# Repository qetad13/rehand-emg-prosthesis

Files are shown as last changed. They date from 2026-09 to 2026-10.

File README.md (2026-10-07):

# ReHand — EMG 기반 손가락 동작 인식 의수 제어

> 졸업작품 · **2026.01 – 2026.10** · 4인 팀 (팀장)

전완부 표면 근전도(sEMG) 4채널을 XIAO ESP32-S3로 1 kHz 샘플링하고, **보드 위에서 직접 CNN 추론**으로 손가락 동작 8가지를 분류해 ESP-NOW로 의수 보드에 명령을 보내는 시스템입니다.
PCB 설계 → 데이터 수집 GUI → PyTorch 학습 → C 코드 자동 생성 → 온디바이스 실시간 추론까지 전 과정을 직접 구현했습니다.

| 항목 | 내용 |
|---|---|
| 입력 | 표면 EMG 4채널, 1000 Hz, 12-bit ADC |
| 출력 | 휴식 / 엄지 / 검지 / 중지 / 약지 / 소지 / 주먹 / 집게 (8클래스) |
| MCU | Seeed XIAO ESP32-S3 (듀얼코어, 추론·샘플링 코어 분리) |
| 모델 | STFT 스펙트로그램 + 3층 Conv2D CNN, 파라미터 6,368개 (float 약 25 KB) |
| 통신 | ESP-NOW (근전도 보드 → 의수 보드, 2바이트 {명령 번호, 힘 세기}) |
| 성능 | 미사용 순서 세션 기준 1초 창 정확도 **97.3%**, 실시간 제어 지연 중앙값 **290 ms** (빠른 모드) |

---

## 시스템 구조

```mermaid
flowchart LR
    subgraph Arm["전완부"]
        S1[EMG 센서 ×4]
    end
    subgraph EMG["근전도 보드 (자체 PCB + XIAO ESP32-S3)"]
        ADC["ADC 1 kHz<br/>(Core 1)"] --> F["IIR 필터<br/>HPF 20 Hz + Notch 60 Hz"]
        F --> RB[링 버퍼]
        RB --> INF["STFT → CNN 추론<br/>(Core 0, FreeRTOS task)"]
        INF --> V["휴식 게이트 + 투표<br/>(오작동 억제)"]
        RB --> ST["힘 세기<br/>(최근 0.2초 RMS / 휴식 RMS)"]
    end
    subgraph Hand["의수 보드"]
        R[ESP-NOW 수신] --> SV[서보 제어]
    end
    S1 -->|Molex SPOX 3핀| ADC
    V -->|ESP-NOW 명령 1~8| R
    ST -->|힘 세기 1~100| R

    subgraph PC["PC (오프라인)"]
        GUI["수집 GUI<br/>(PySide6)"] --> CSV[(CSV + 라벨 순서)]
        CSV --> TR["PyTorch 학습<br/>train_emg.py"]
        TR -->|"emg_model.h<br/>emg_test_vectors.h"| INF
    end
    ADC -.->|MODE_RECORD, USB 시리얼| GUI
```

### 데이터 파이프라인

1. **수집** — 펌웨어를 `MODE_RECORD`로 올리고 GUI가 5초 힘주기 / 5초 쉬기를 안내하며 녹화 (1세션 = 8동작 × 10초 = 80초)
2. **전처리** — 4차 Butterworth HPF 20 Hz + 60 Hz 노치 (PC와 ESP32에서 **같은 SOS 계수**로 계산)
3. **특징** — 창마다 채널별 z-score 정규화 → Hamming 창 STFT → 주파수 밴드 평균 → log 파워
4. **모델** — Conv(8) → Conv(16) → Conv(32) → Global Avg Pool → FC. BatchNorm은 내보낼 때 Conv에 접어(fold) 넣음
5. **내보내기** — 가중치·필터 계수·클래스 이름을 C 헤더로 생성, PC 예측값을 **골든 테스트 벡터**로 함께 내보냄
6. **온디바이스** — Core 1은 1 kHz 샘플링만, Core 0은 추론 태스크. 출력은 투표 로직을 거쳐 ESP-NOW로 전송

---

## 폴더 구조

```
rehand-emg-prosthesis/
├─ hardware/                 KiCad 프로젝트 (근전도 보드)
│  ├─ v1/                    초기 보드: 회로도 · PCB · gerber/
│  └─ v2/                    현재 보드 (배터리 · 버튼 추가): 회로도 · PCB · gerber/
├─ collector/                데이터 수집 GUI (PySide6 + pyserial)
│  └─ emg_collector_v4.py
├─ training/                 학습 + ESP32용 C 헤더 생성
│  ├─ train_emg.py           python train_emg.py [--fast]
│  ├─ data/Fixed/            고정 순서 세션 15개 (학습/검증)
│  ├─ data/Random/           무작위 순서 세션 5개 (테스트 전용)
│  ├─ output/                정확 모드 결과 (report, 그림, 모델)
│  └─ output_fast/           빠른 모드 결과
├─ firmware/                 Arduino (XIAO ESP32-S3)
│  ├─ esp32_emg_realtime/    녹화 · 센서 점검 · 실시간 판단 · 재생 (모드 전환)
│  ├─ esp32_emg_test/        PC ↔ ESP32 결과 일치 검증 (골든 테스트)
│  └─ esp32_emg_bench/       단계별 연산 시간 측정 (STFT+CNN vs 시간영역 특징)
└─ docs/
   ├─ hand_board_patch.md    의수 보드 ESP-NOW 수신부 수정 내역
   └─ images/                결과 그림
```

---

## 하드웨어

<p align="center">
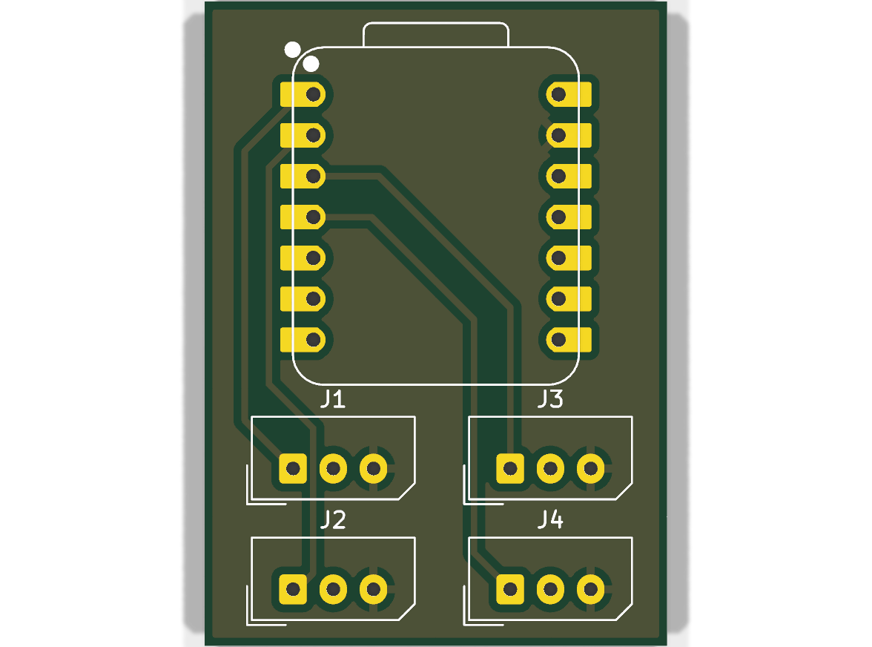
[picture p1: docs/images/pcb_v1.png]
  
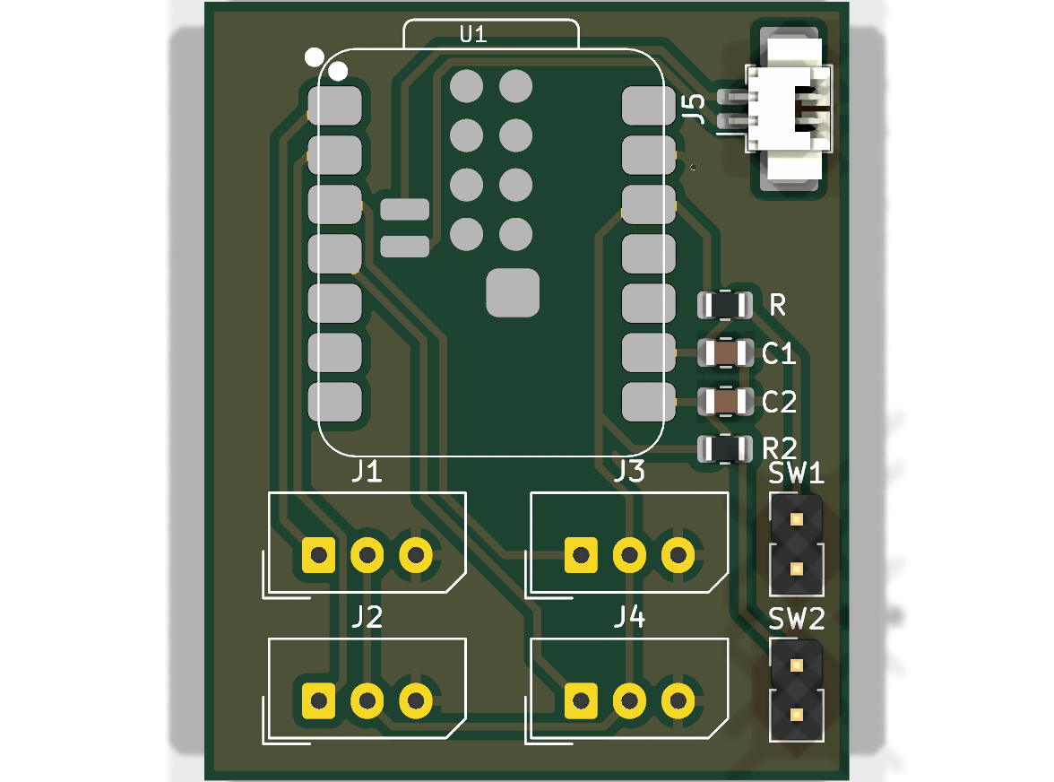
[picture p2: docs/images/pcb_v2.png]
  
  <br><sub>왼쪽 v1 · 오른쪽 v2 (현재)</sub>
</p>

| | v1 | v2 (현재) |
|---|---|---|
| 크기 | 28.75 × 40 mm | 33.2 × 40 mm |
| MCU 실장 | XIAO ESP32-S3 DIP 풋프린트 | XIAO ESP32-S3 **SMD** 풋프린트 (하단 BAT 패드 사용) |
| 센서 입력 | Molex SPOX 3핀 ×4 (신호 / 3V3 / GND → A0~A3) | 동일 |
| 전원 | USB | **J5 PicoBlade 2핀** → XIAO BAT 패드 (배터리 연결) |
| 입력 버튼 | 없음 | **SW1 · SW2** (D7 · D8), 풀업 저항 + 디바운스 커패시터 (0805) |
| 회로도 | [schematic_v1.svg](docs/images/schematic_v1.svg) | [schematic_v2.svg](docs/images/schematic_v2.svg) |

- 브레드보드 배선에서 생기던 접촉 불량과 잡음을 줄이기 위해 전용 보드로 제작
- v2에서는 착용형으로 쓰기 위해 배터리 입력을 추가하고, 버튼 2개를 하드웨어 풀업·RC 디바운스와 함께 넣음
  - **SW1**: 근전도 모드 ↔ 매크로 모드 전환 (보드 LED가 켜지면 매크로 모드)
  - **SW2**: 매크로 모드에서 다음 동작 선택 (명령 11~19). 근전도 모드에서는 사용자 보정 기능 자리로 예약
  - 버튼은 별도 FreeRTOS 태스크가 10 ms마다 읽어 1 kHz 측정 루프에 영향이 없음. 스위치가 없는 보드에서는 시리얼 `1`/`2` 또는 BOOT 버튼(짧게/길게)으로 대신 조작

---

## 힘 세기 → 의수 속도

CNN은 창마다 채널을 z-score 정규화한 뒤 **모양**만 보기 때문에 "얼마나 세게" 힘을 줬는지는 알 수 없습니다.
그래서 동작 종류는 CNN이, 세기는 신호 크기로 따로 재서 함께 보냅니다.

- **세기(배)** = 최근 0.2초 RMS ÷ 휴식 RMS, 4채널 중 최댓값 (`emg_strength()`)
- **세기(%)** = 휴식 게이트 크기를 0%, 동작별 기준을 100%로 놓고 환산 → 1~100으로 전송 (휴식·매크로 모드는 0 = 기본 속도)
- **동작별 기준**: 같은 힘이어도 동작마다 신호 크기가 크게 달라서(엄지 약 6배, 약지 약 40배) 녹화 20세션에서 "인식 직후 0.5초 평균"의 중앙값을 동작별로 사용
- **안정화**: 동작 시작 순간에는 바로 반영하고 이후 지수 평활(α = 0.5). 필요하면 약/강, 약/중/강 단계 출력 + 히스테리시스로 전환 가능
- **보정 지원**: 동작이 끝날 때마다 시리얼에 `세기 요약`(처음 0.5초 평균 / 이후 평균)을 출력해 센서를 다시 붙였을 때 기준을 쉽게 다시 맞춤
- 인식 직후 첫 값은 근전도가 아직 커지는 중이라 들쭉날쭉하므로, 의수 보드는 첫 값으로 속도를 고정하지 않고 움직이는 동안 계속 갱신하도록 함 → [docs/hand_board_patch.md](docs/hand_board_patch.md)

---

## 성능

평가는 **학습에 쓰지 않은 Random 세션 5개**(동작 순서를 무작위로 섞어 녹화, 총 6.7분)로 했습니다. 고정 순서만 학습하면 "순서"를 외울 수 있기 때문에 테스트 세트를 순서가 다른 세션으로 분리했습니다.

### 분류 정확도

| 지표 | 정확 모드 | 빠른 모드 |
|---|---|---|
| 창 단위 정확도 (8클래스) | **97.3%** | 95.1% |
| 창 단위 정확도 (휴식 제외 7동작) | 94.6% | 93.7% |
| 수축 구간 다수결 | 97.5% (39/40) | 97.5% (39/40) |

클래스별 (정확 모드): 휴식 100%, 엄지 92%, 검지 98%, 중지 95%, 약지 100%, 소지 92%, 주먹 100%, 집게 85%

<p align="center">
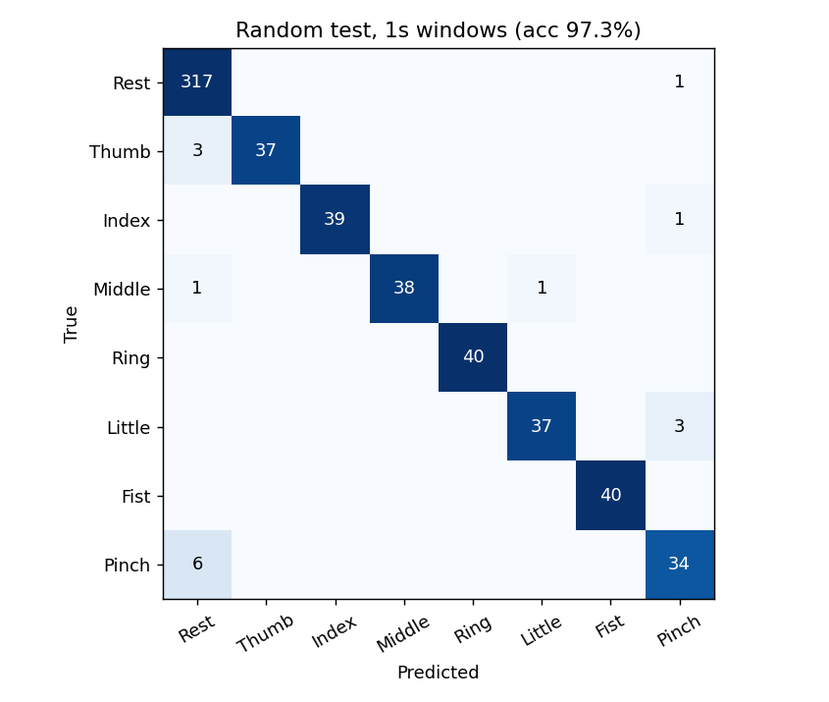
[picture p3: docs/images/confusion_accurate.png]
  
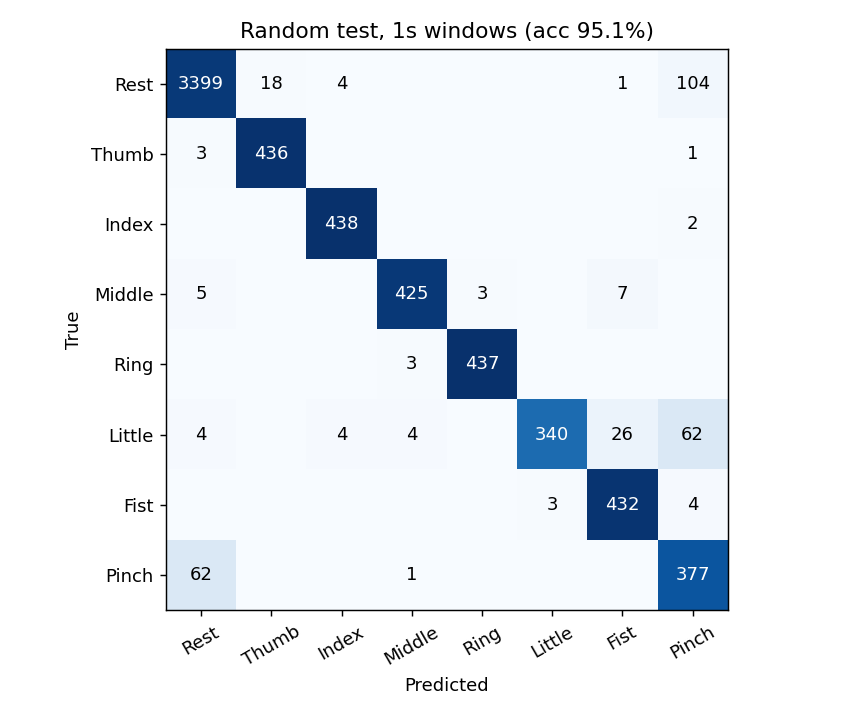
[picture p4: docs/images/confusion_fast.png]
  
</p>

### 실시간 제어 (실제 판단 주기와 투표 로직을 그대로 재현한 시뮬레이션)

| 지표 | 정확 모드 | 빠른 모드 |
|---|---|---|
| 판단 창 / 주기 | 1.0 s / 500 ms | 0.5 s / 50 ms |
| 근전도 시작 → 올바른 출력 (중앙값) | 1007 ms | **290 ms** |
| 근전도 시작 → 올바른 출력 (90%) | 1482 ms | 790 ms |
| 힘 뺀 뒤 출력 해제 (중앙값) | 394 ms | **243 ms** |
| 동작 인식 성공 / 놓침 | 35 / 0 | 35 / 0 |
| 잘못된 손가락 출력 (6.7분) | **0회** | 6회 |
| 휴식 중 오작동 비율 | 0.0% | 0.4% |

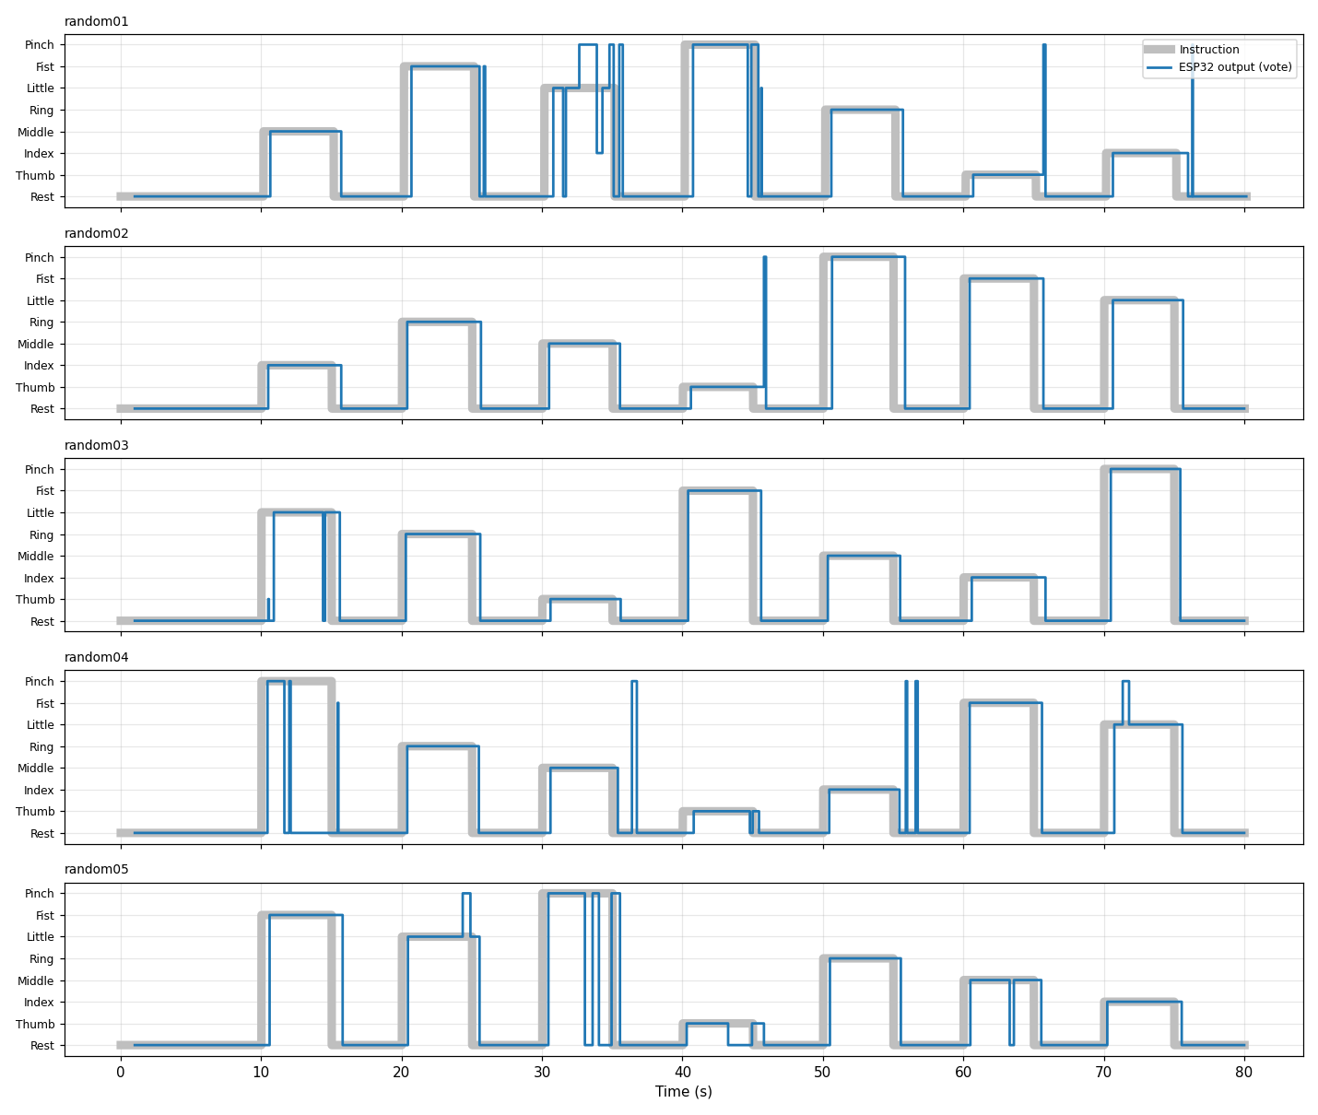
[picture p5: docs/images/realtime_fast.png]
realtime


### 경량화

| | 기존 MATLAB 모델 | 이 프로젝트 (정확) | 이 프로젝트 (빠른) |
|---|---|---|---|
| 1회 판단 곱셈 수 | 약 231 M | 0.44 M | 0.14 M |
| 파라미터 | – | 6,368 (≈25 KB) | 6,368 (≈25 KB) |

연산량을 **약 500~1600배** 줄여 ESP32-S3에서 50 ms 주기 추론이 가능해졌습니다. 펌웨어는 추론이 주기 안에 끝나지 않으면 `판단 건너뜀` 카운터로 표시합니다.

---

## 트러블슈팅

### 1. 여러 채널이 같은 필터 상태를 공유하는 문제
- **증상**: 채널을 4개로 늘리자 한 채널에 힘을 줘도 다른 채널 파형이 같이 흔들림
- **원인**: 사용하던 `EMGFilters` 라이브러리가 LPF/HPF/노치 필터의 내부 상태를 **파일 전역 변수**로 갖고 있어, 채널마다 객체를 만들어도 상태가 섞임
- **해결**: 필터 상태를 클래스 멤버로 옮겨 인스턴스마다 독립되게 수정 ([EMGFilters.h](firmware/esp32_emg_realtime/EMGFilters.h))

### 2. 녹화 중 샘플 손실 → 라벨 밀림
- **증상**: 80초 녹화인데 CSV 줄 수가 모자라거나, 뒤쪽 동작 구간이 앞 동작 신호와 섞임
- **원인**: 샘플링과 USB 시리얼 전송을 같은 루프에서 하다 보니, PC 쪽 읽기가 잠깐 멈추면 `Serial.write`가 막혀 1 kHz 샘플링이 밀림. 또 GUI가 녹화를 시작하기 전에 쌓인 옛 데이터가 녹화 앞부분에 섞임
- **해결**
  - 샘플링(Core 1)과 전송(Core 0)을 분리하고 16k 샘플 링 버퍼로 연결
  - 1초 이상 밀리면 오래된 데이터를 버리고 실시간으로 다시 맞춤, 이때 LED를 켜서 불량 녹화를 바로 알 수 있게 함
  - 학습 코드에서 길이가 5초 ± 5%를 벗어난 구간은 자동으로 제외

### 3. 시리얼 전송 중 깨진 값
- **증상**: `73-6.0`처럼 두 값이 붙은 줄 때문에 CSV 파싱 실패
- **해결**: 숫자로 변환 불가능한 값은 NaN 처리 후 앞뒤 값으로 채움 (`pd.to_numeric(errors="coerce").ffill()`)

### 4. 센서 접촉 불량 데이터가 학습을 망침
- **증상**: 특정 세션이 섞이면 전체 정확도가 크게 떨어짐. 원인을 찾아보면 전극이 떠 있던 세션
- **해결**: 학습 전 자동 품질 검사 추가
  - 수축 구간 RMS가 휴식 대비 1.3배 미만인 세션 자동 제외
  - 어떤 동작에도 반응하지 않는 채널 / 휴식 때부터 잡음이 큰 채널 경고
  - 펌웨어 `MODE_CHECK`로 녹화 전에 채널별 흔들림 · 클리핑 확인

### 5. 학습과 실시간 입력이 달라서 생기는 정확도 저하
- **증상**: PC 검증 정확도는 높은데 보드에 올리면 판단이 불안정
- **원인**: 녹화용 코드와 판단용 코드의 ADC 읽기·필터 경로가 달랐음
- **해결**
  - 녹화(`MODE_RECORD`)와 판단(`MODE_RUN`)을 한 스케치로 합치고 같은 `readEmgInput()`을 사용
  - PC 필터도 `filtfilt`(양방향) 대신 기기와 같은 인과 필터 `sosfilt`를 파일 처음부터 연속 적용
  - 학습 스크립트가 PC 예측 확률을 `emg_test_vectors.h`로 내보내고, `esp32_emg_test`에서 ESP32 결과와 비교 → **PC와 C 구현의 확률 차이까지 검증**

### 6. MATLAB 모델을 MCU에 올릴 수 없는 문제
- **원인**: 기존 모델은 1회 판단에 약 2.3억 번 곱셈 → ESP32에서 실시간 불가
- **해결**: 입력을 STFT 밴드 평균(채널당 22×24 또는 13×14)으로 줄이고, 3층 소형 CNN + Global Average Pooling으로 FC 파라미터를 최소화. BN을 Conv에 접어서 추론 시 연산 제거
- `esp32_emg_bench`로 필터 / STFT / CNN 단계별 시간과 시간영역 특징(MAV·RMS·WL·ZC·SSC) 방식을 비교해 구조를 결정

### 7. 반응 속도 vs 오작동 트레이드오프
- **문제**: 1초 창 · 0.5초 주기는 오작동이 0회지만 반응이 1초 가까이 늦어 의수로 쓰기 답답함
- **해결**: 0.5초 창을 50 ms마다 판단하는 빠른 모드 추가, 대신 늘어나는 오판을 규칙으로 억제
  - **휴식 게이트**: 모든 채널 RMS가 휴식 기준의 2배 미만이면 무조건 휴식
  - **히스테리시스 투표**: 켜기는 3회 연속, 다른 동작으로 전환은 5회 연속, 끄기는 휴식 1회
  - 라벨을 창의 "끝부분" 상태 + 사람 반응 지연(50~150 ms)으로 맞춰 힘을 빼면 빨리 풀리도록 학습
- **1차 결과**: 제어 지연 1007 ms → **290 ms**, 해제 394 ms → 104 ms. 하지만 6.7분 동안 엉뚱한 손가락 출력이 **15회**
- **2차 조정**: 출력이 짧게 바뀌었다 돌아오는 오출력을 줄이기 위해 출력을 바꾸는 조건을 더 엄격하게 함
  - 다른 동작으로 전환: 5회 → **8회 연속**
  - 끄기: 휴식 1회 → **3회 연속** (휴식 판단 한 번에 껐다 켜지는 깜빡임 방지)
  - **최소 유지 시간 0.5초**: 출력이 바뀐 뒤 10회 판단 동안은 다시 바꾸지 않음
  - PC 시뮬레이션(`vote_sequence`)과 ESP32(`emg_vote_update`)에 같은 규칙을 넣고 파라미터는 `emg_model.h`로 자동 생성
- **최종 결과**: 제어 지연 **290 ms 유지**, 오출력 15회 → **6회**, 대신 해제는 104 ms → 243 ms로 늘어남

### 8. 시리얼 출력 때문에 추론이 밀림
- **증상**: PC에서 시리얼 모니터를 닫으면 판단 주기가 늘어짐
- **원인**: USB CDC 버퍼가 차면 `Serial.printf`가 블로킹
- **해결**: 판단 모드에서 `Serial.setTxTimeoutMs(0)`로 PC가 안 읽으면 출력 버림, 빠른 모드는 출력 변경 시 + 1초마다만 출력

### 9. 의수가 명령을 받지만 움직이지 않음
- **원인 1**: 의수 보드의 ESP-NOW 콜백이 플래그만 세우고 `loop()`에서 확인하지 않음
- **원인 2**: 수신 조건이 `cmd <= 6`이라 새로 추가한 주먹(7) · 집게(8)가 무시됨
- **해결**: `loop()`에서 플래그를 확인해 실행 (서보 버스를 WiFi 태스크 콜백 안에서 쓰지 않도록), 범위를 1~8로 확장. 근전도 보드는 0.5초마다 현재 명령을 재전송해 패킷 손실에도 복구 → [docs/hand_board_patch.md](docs/hand_board_patch.md)

---

## 실행 방법

### 1. 설치
```bash
pip install -r training/requirements.txt -r collector/requirements.txt
```

### 2. 데이터 수집
1. `firmware/esp32_emg_realtime/esp32_emg_realtime.ino`에서 `#define RUN_MODE MODE_CHECK`로 업로드 → 채널 상태 확인
2. `MODE_RECORD`로 업로드 후 `python collector/emg_collector_v4.py`
3. 고정 순서는 `training/data/Fixed/`, 무작위 순서는 `training/data/Random/`에 저장 (순서는 `_order.txt`로 자동 기록)

### 3. 학습
```bash
python training/train_emg.py          # 정확 모드
python training/train_emg.py --fast   # 빠른 모드
```
생성된 `emg_model.h`, `emg_test_vectors.h`가 `firmware/`의 세 스케치 폴더에 자동 복사됩니다.

### 4. 검증 및 실행
| 스케치 | 용도 |
|---|---|
| `esp32_emg_test` | PC 결과와 일치 여부 확인 (`8 / 8 통과`) |
| `esp32_emg_bench` | 단계별 연산 시간 측정 |
| `esp32_emg_realtime` (`MODE_RUN`) | 실시간 판단 + ESP-NOW 전송 |
| `esp32_emg_realtime` (`MODE_REPLAY`) | 센서 없이 저장 데이터로 판단 흐름 확인 |

Arduino IDE 설정: 보드 `XIAO_ESP32S3`, `USB CDC On Boot: Enabled`

---

## 변경 이력

| 날짜 | 변경 내용 |
|---|---|
| 2026-10-07 | **힘 세기 전송**: 동작 종류와 함께 힘 세기(1~100)를 2바이트 패킷으로 전송, 의수 보드에서 서보 속도로 사용. 동작별 100% 기준, 평활화, 단계 출력 옵션, 세기 요약 출력 추가 |
| 2026-10-06 | **근전도 / 매크로 모드**: SW1로 모드 전환, SW2로 매크로 동작(명령 11~19) 선택. 버튼 전용 FreeRTOS 태스크, 시리얼·BOOT 버튼 대체 입력 |
| 2026-10-02 | **빠른 모드 투표 규칙 강화**: 끄기 3회 연속, 전환 8회 연속, 최소 유지 0.5초 추가 → 오출력 15회 → 6회 (6.7분 기준) |
| 2026-09-30 | **PCB v2**: XIAO SMD 실장, 배터리 커넥터, 버튼 2개(풀업 + RC 디바운스) 추가 |
| 2026-09-30 | 저장소 공개: 하드웨어 · 수집 GUI · 학습 · 펌웨어 · 문서 정리 |

---

## 기술 스택
`Python` `PyTorch` `NumPy/SciPy` `PySide6` · `C/C++ (Arduino, FreeRTOS)` · `KiCad`

## 라이선스 / 출처
- `firmware/esp32_emg_realtime/EMGFilters.*`: OYMotion Inc. (BSD-3-Clause), 채널별 상태 분리 수정

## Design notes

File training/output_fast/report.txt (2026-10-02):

=== Random 세션(순서 섞은 데이터) 시험 결과 ===
1초 단위 정확도 (휴식 포함 8종): 95.1%
1초 단위 정확도 (휴식 제외 동작 7종): 93.7%
한 번 힘주기(수축 구간) 다수결: 97.5% (39/40)
클래스별 1초 단위 정답률: Rest 96%, Thumb 99%, Index 100%, Middle 97%, Ring 99%, Little 77%, Fist 98%, Pinch 86%

=== 실시간 흉내 (50ms마다 판단 / 켜기: 최근 3번 중 3번, 바꾸기: 연속 8번, 끄기: Rest 3번 연속, 최소 유지 0.5초, 휴식 게이트 2.0) ===
안정 구간 정확도: 96.5%
휴식 중 잘못 움직임 판단 비율: 0.4%
힘주기 시작 -> 올바른 판단까지 걸린 시간(중앙값): 0.48초
힘 빼기 -> 손가락 판단이 풀릴 때까지 걸린 시간(중앙값): 0.54초
근전도 시작 -> 올바른 판단 (제어 지연): 중앙값 290ms, 90% 790ms
근전도 끝 -> 풀림: 중앙값 243ms
손가락 동작 인식: 35번 성공 / 0번 놓침
엉뚱한 손가락이 켜진 횟수: 6번 (총 6.7분 동안)

=== ESP32 부담 ===
가중치 수: 6368개 (float 기준 약 25KB)
한 번 판단에 곱셈 약 0.14백만 번 (MATLAB 모델은 약 231백만 번)
최고 시점: epoch 14

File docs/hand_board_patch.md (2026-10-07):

# 의수 보드 코드 수정 (ESP-NOW 명령 실행)

현재 의수 코드는 ESP-NOW로 명령을 **받기만 하고 실행하지 않습니다.**
`onEspNowReceive()`가 `g_newEspNowCommand`를 true로 바꾸지만, `loop()`에서 이걸 확인하는 곳이 없습니다.

`loop()`를 아래처럼 바꾸면 됩니다. (추가된 부분은 가운데 블록 하나)

```cpp
void loop() {
  static uint32_t last_cmd_ms = 0;

  if (HOMING_isBusy()) {
    while (Serial.available()) { Serial.read(); }
    vTaskDelay(pdMS_TO_TICKS(5));
    return;
  }

  // ---- ESP-NOW로 받은 명령 실행 (근전도 보드가 0.5초마다 보냄) ----
  if (g_newEspNowCommand) {
    g_newEspNowCommand = false;
    static uint8_t lastEspNowCmd = 0;
    uint8_t cmd = g_receivedCommand;
    if (cmd != lastEspNowCmd) {      // 같은 명령이 반복해서 오면 무시
      lastEspNowCmd = cmd;
      Serial.print("[ESP-NOW] Received command: ");
      Serial.println(cmd);
      executeHandCommand(cmd);
    }
  }

  checkAndEnforceSoftLimits();
  checkSerialHandCommand();
  vTaskDelay(pdMS_TO_TICKS(5));
}
```

참고: 명령 실행을 수신 콜백(`onEspNowReceive`) 안에서 하지 않고 `loop()`에서 하는 이유는,
콜백은 WiFi 태스크에서 돌기 때문에 거기서 서보 버스(시리얼, 뮤텍스)를 쓰면 WiFi가 멈출 수 있어서입니다.

## 근전도 보드가 보내는 명령 (9/24 기준, 8가지)

| 근전도 판단 | 명령 번호 |
|---|---|
| 엄지 | 1 |
| 검지 | 2 |
| 중지 | 3 |
| 약지 | 4 |
| 소지 | 5 |
| 휴식 | 6 |
| 주먹 | 7 |
| 집게 | 8 |

**주의:** 의수 코드의 수신 콜백 `onEspNowReceive()`에 `if (cmd >= 1 && cmd <= 6)`가 있으면
7, 8이 무시됩니다. `cmd <= 8`로 바꿔주세요. 시리얼 테스트용 `checkSerialHandCommand()`도 `'8'`까지 받게 바꾸면 편합니다.

번호를 바꾸려면 근전도 보드의 `esp32_emg_realtime.ino`에서 `handCmdFor()`만 수정하면 됩니다.

## 힘 세기 받기 (세게 = 빠르게)

근전도 보드가 이제 **2바이트 {명령 번호, 힘 세기}** 를 보냅니다. (판단할 때마다, 빠른 모드 기준 50ms마다)

| 힘 세기 값 | 의미 |
|---|---|
| 1~100 | 손가락 동작 중. 클수록 세게 힘을 준 것 |
| 0 | 세기 정보 없음 (휴식, 매크로 모드) -> 기본 속도로 움직이면 됨 |

의수 코드에서 바꿀 곳은 세 군데입니다. (변수/함수 이름은 실제 의수 코드에 맞춰 주세요)

```cpp
volatile uint8_t g_receivedStrength = 0;

// 1) 수신 콜백: 길이가 1이어도 2여도 받도록
//    (len == 1 인지 검사하는 줄이 있으면 len >= 1 로 바꾸기)
g_receivedCommand  = data[0];
g_receivedStrength = (len >= 2) ? data[1] : 0;
g_newEspNowCommand = true;

// 2) 세기 -> 서보 속도
//    SPEED_MIN/MAX/DEFAULT는 지금 서보 위치 명령에 넣고 있는 속도 값 기준으로 정하기
uint16_t speedFromStrength(uint8_t s) {
  if (s == 0) return SPEED_DEFAULT;
  return SPEED_MIN + (uint32_t)(SPEED_MAX - SPEED_MIN) * s / 100;
}

// 3) loop(): 같은 명령이 반복해서 와도 "속도"는 계속 갱신
if (g_newEspNowCommand) {
  g_newEspNowCommand = false;
  static uint8_t lastEspNowCmd = 0;
  uint8_t cmd = g_receivedCommand;
  g_handSpeed = speedFromStrength(g_receivedStrength);   // 매번 갱신
  if (cmd != lastEspNowCmd) {
    lastEspNowCmd = cmd;
    executeHandCommand(cmd);          // 안에서 서보 위치 명령을 보낼 때 g_handSpeed 사용
  } else {
    updateHandSpeed();                // 움직이는 중인 서보에 같은 목표 위치 + 새 속도를 다시 보냄
  }
}
```

**주의: 명령이 처음 바뀐 순간의 세기 값 하나로 속도를 고정하지 마세요.**
동작이 인식되는 순간에는 근전도가 아직 커지는 중이라, 같은 힘으로 줘도 첫 값이 10~100까지 들쭉날쭉합니다
(녹화 데이터로 확인). 0.1~0.2초 뒤에 제 값이 되므로, 움직이는 동안 들어오는 값으로 속도를 계속 바꿔야 합니다.

근전도 보드 쪽 설정은 `esp32_emg_realtime.ino`의 "힘 세기" 부분에 있습니다.
(`STRENGTH_LEVELS`를 2나 3으로 바꾸면 연속값 대신 약/강, 약/중/강 단계 값으로 보냄)

## 매크로 모드 명령 (11~19)

근전도 보드에서 SW1로 매크로 모드에 들어가면, 근전도 판단 대신 SW2로 고른 동작 번호(11~19)를 판단 주기마다 보냅니다.
의수 보드의 수신 조건이 `cmd <= 8`이면 이 명령들이 무시되므로, `11 <= cmd <= 19`도 받도록 넓히고 번호별 동작을 `executeHandCommand()`에 추가해야 합니다.
매크로 이름과 번호는 근전도 보드 `esp32_emg_realtime.ino`의 `MACROS[]`에서 바꿀 수 있습니다.

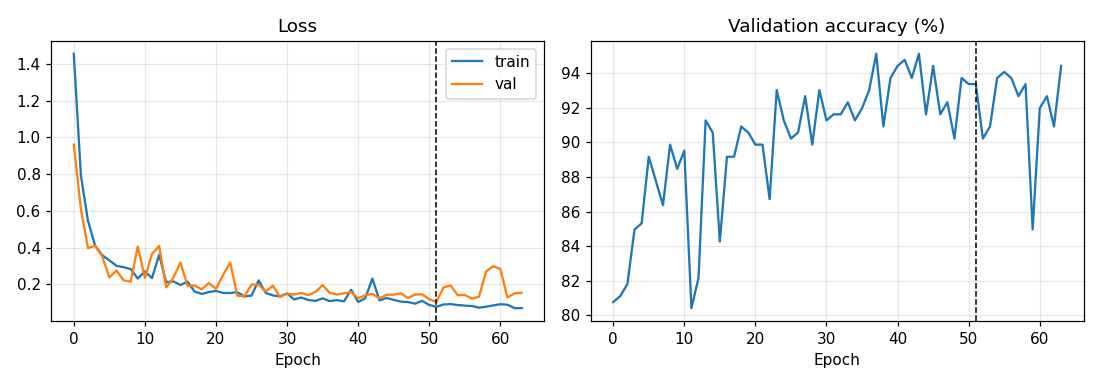
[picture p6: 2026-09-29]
docs/images/training_curve_accurate.png

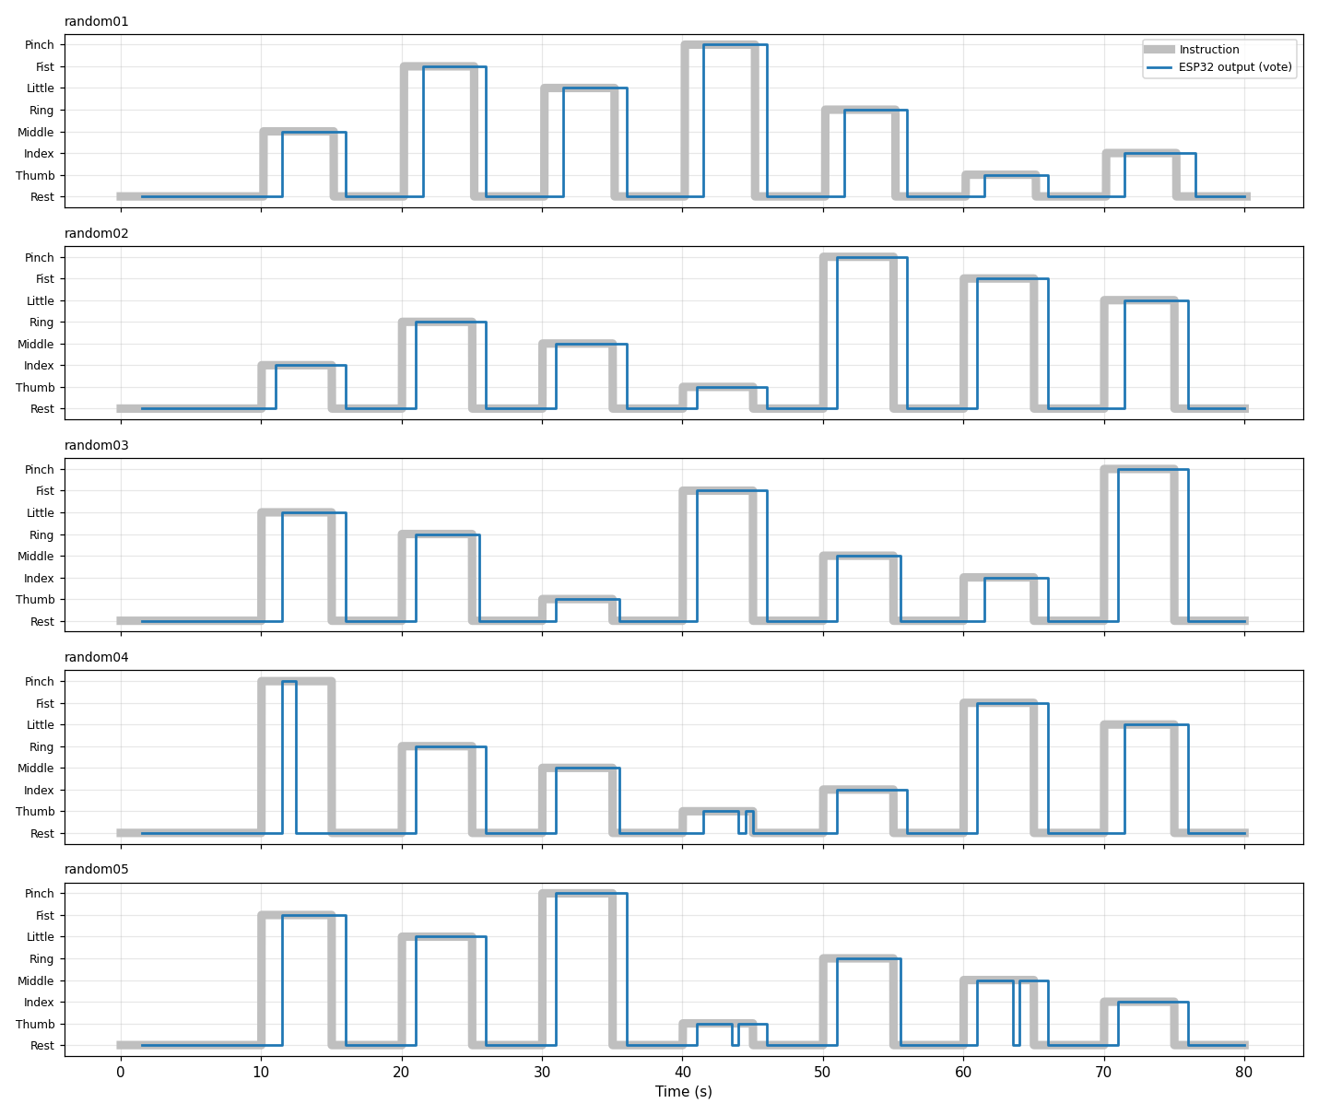
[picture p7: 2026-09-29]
docs/images/realtime_accurate.png

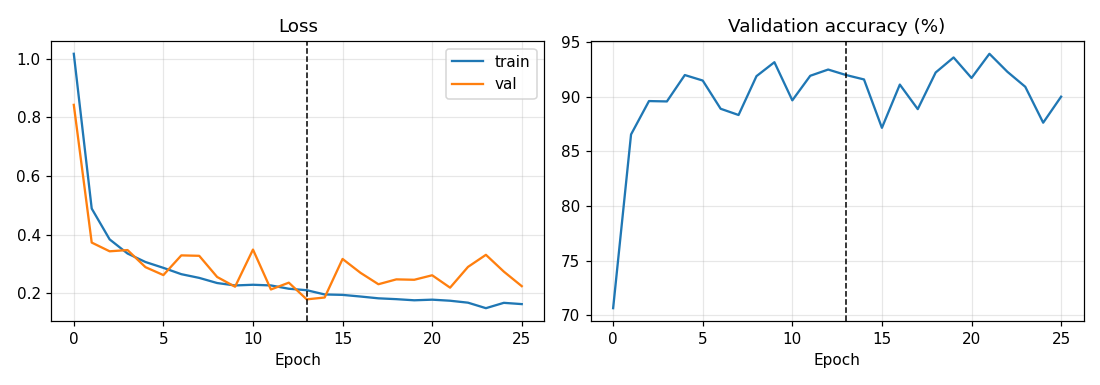
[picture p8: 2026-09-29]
training/output_fast/training_curve.png

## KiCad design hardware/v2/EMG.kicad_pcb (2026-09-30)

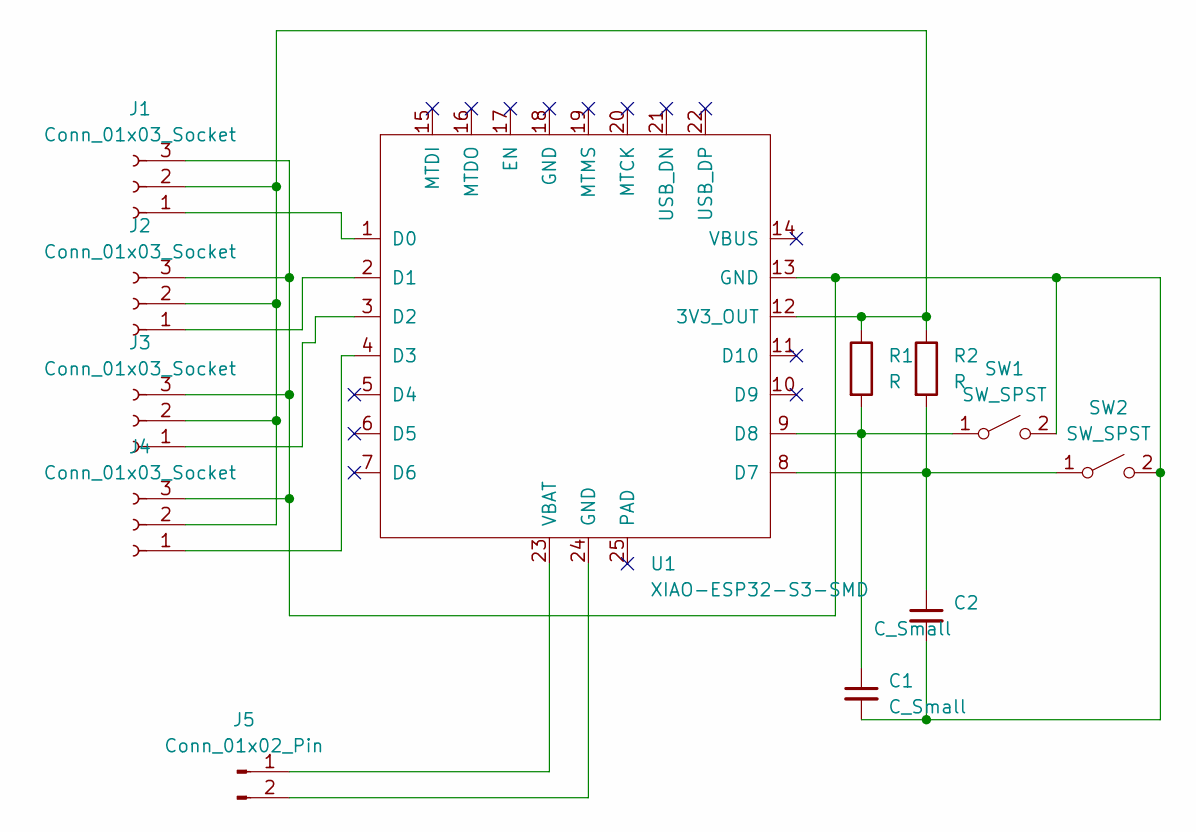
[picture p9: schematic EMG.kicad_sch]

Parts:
C1, C2: C_Small; C_0805_2012Metric
J1, J2, J3, J4: Conn_01x03_Socket; Molex_SPOX_5267-03A_1x03_P2.50mm_Vertical
J5: Conn_01x02_Pin; Molex_PicoBlade_53261-0271_1x02-1MP_P1.25mm_Horizontal
R1, R2: R; R_0805_2012Metric
SW1, SW2: SW_SPST; PinHeader_1x02_P2.54mm_Vertical
U1: XIAO-ESP32-S3-SMD

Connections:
unnamed: J1.1, U1.1 (D0)
unnamed 1: J1.2, J2.2, J3.2, J4.2, R1.1, R2.1, U1.12 (3V3_OUT); also elsewhere on the board
unnamed: C1.2, C2.2, J1.3, J2.3, J3.3, J4.3, SW1.2 (B), SW2.2 (B), U1.13 (GND)
unnamed: J2.1, U1.2 (D1)
unnamed: J3.1, U1.3 (D2)
unnamed: J4.1, U1.4 (D3)
unnamed: J5.1, U1.23 (VBAT)
unnamed: J5.2, U1.24 (GND)
unnamed 8: C1.1, R1.2, SW1.1 (A), U1.9 (D8); also elsewhere on the board
unnamed: C2.1, R2.2, SW2.1 (A), U1.8 (D7)

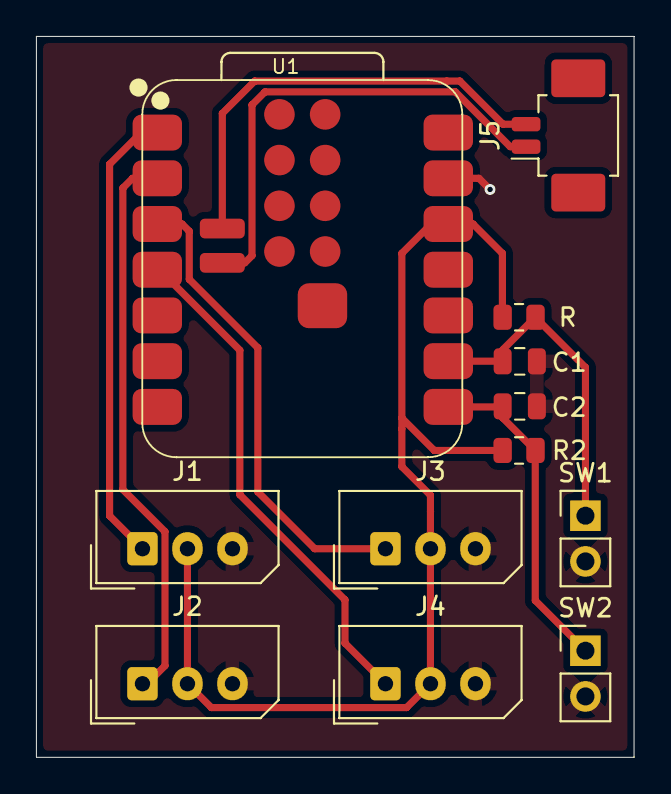
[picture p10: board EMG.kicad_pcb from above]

Board: 2 copper layers, 33.2 x 40.0 mm, 12 parts (0 on the bottom side), 10 nets.

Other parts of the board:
R: R; R_0805_2012Metric

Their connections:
unnamed 1: R.1; also elsewhere on the board
unnamed 8: R.2; also elsewhere on the board

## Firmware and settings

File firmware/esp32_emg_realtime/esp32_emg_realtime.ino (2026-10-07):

// =====================================================================
// EMG 녹화 + 실시간 손가락 동작 판단 (XIAO ESP32-S3)
//
// 녹화(MODE_RECORD)와 판단(MODE_RUN)이 같은 readEmgInput()을 쓰기 때문에
// 학습 데이터와 실시간 입력이 항상 똑같습니다. 필터는 AI 쪽(emg_infer)에서 겁니다.
//
//   MODE_RECORD : GUI로 녹화할 때 (예전 녹화 코드 대신 이걸 올리면 됨)
//   MODE_CHECK  : 센서 상태 확인 (채널별 평균/흔들림/클리핑)
//   MODE_RUN    : 0.5초마다 판단 (새 데이터로 학습한 모델이 들어간 뒤에 사용)
//   MODE_REPLAY : 센서 없이 저장된 데이터로 판단 흐름 확인
//
// MODE_RUN에서는 판단 결과(어떤 손가락)와 함께 힘 세기(1~100)도 의수로 보냅니다.
// (아래 "힘 세기" 참고. 세게 주면 큰 값 -> 의수 보드가 모터 속도로 사용)
//
// MODE_RUN 안에서는 스위치로 두 가지 동작 모드를 오갑니다. (아래 "모드 전환" 참고)
//   근전도 모드 : 근전도 판단 결과를 의수로 보냄 (기본)
//   매크로 모드 : 근전도를 쓰지 않고, 스위치로 고른 동작(명령 11~19)을 의수로 보냄
// =====================================================================
#include "emg_infer.h"
#include "emg_test_vectors.h"
#include "EMGFilters.h"   // 채널마다 필터 상태를 따로 갖도록 수정된 버전
#include <WiFi.h>
#include <esp_now.h>

// ---------------------------------------------------------------------
// 사용자 설정
// ---------------------------------------------------------------------
#define MODE_REPLAY 0
#define MODE_CHECK  1
#define MODE_RUN    2
#define MODE_RECORD 3
#define RUN_MODE    MODE_RUN

// 녹화는 항상 4채널 (CSV의 Ch 00, Ch 01, Ch 02, Ch 03 순서)
// 판단에는 그중 모델이 쓰는 채널(emg_model.h의 EMG_CHANNEL_IDX)만 사용
#define REC_CH 4
static const int EMG_PINS[REC_CH] = {A0, A1, A2, A3};

// 녹화(MODE_RECORD)와 판단(MODE_RUN)이 아래 두 함수를 똑같이 사용합니다.
// 여기를 바꾸면 반드시 데이터를 새로 녹화하고 새로 학습해야 합니다.
static EMGFilters s_emgFilter[REC_CH];

static void setupEmgInput() {
  analogReadResolution(12);
  for (int c = 0; c < REC_CH; ++c) {
    pinMode(EMG_PINS[c], INPUT);
    s_emgFilter[c].init(SAMPLE_FREQ_1000HZ, NOTCH_FREQ_60HZ, true, true, true);
  }
}

static int s_lastRaw[REC_CH];   // 필터 전 원본 값 (상태 확인용)

[[maybe_unused]] static int readEmgInput(int ch) {
  const int raw = analogRead(EMG_PINS[ch]);
  s_lastRaw[ch] = raw;
  return s_emgFilter[ch].update(raw);
}

// ---------------------------------------------------------------------
// 의수 보드로 무선 전송 (ESP-NOW, MODE_RUN에서만 동작)
// ---------------------------------------------------------------------
#define USE_ESPNOW 1

// 보내는 내용: 2바이트 {명령 번호, 힘 세기}
//   힘 세기 1~100 : 근전도 모드에서 손가락 동작 중일 때 (클수록 세게 -> 의수는 빠르게)
//   힘 세기 0     : 세기 정보 없음 (휴식, 매크로 모드) -> 의수는 기본 속도로
// 의수 보드가 아직 1바이트만 받는 코드라면 0으로 바꾸면 예전처럼 명령 번호만 보냅니다.
#define SEND_STRENGTH 1

// 판단 결과 -> 의수 보드 명령 번호 (팀에서 정한 번호, 이름으로 연결해서 동작 순서가 바뀌어도 안전)
//   1 엄지, 2 검지, 3 중지, 4 약지, 5 소지, 6 휴식, 7 주먹, 8 집게
static uint8_t handCmdFor(int gesture) {
  const char *n = EMG_CLASS_NAMES[gesture];
  if (!strcmp(n, "Thumb"))  return 1;
  if (!strcmp(n, "Index"))  return 2;
  if (!strcmp(n, "Middle")) return 3;
  if (!strcmp(n, "Ring"))   return 4;
  if (!strcmp(n, "Little")) return 5;
  if (!strcmp(n, "Rest"))   return 6;
  if (!strcmp(n, "Fist"))   return 7;
  if (!strcmp(n, "Pinch"))  return 8;
  return 6;  // 모르는 동작이면 휴식
}

// 의수 보드 MAC 주소. 모르면 FF로 두면 근처 모든 ESP-NOW 수신기로 방송(broadcast)
static uint8_t HAND_MAC[6] = {0xFF, 0xFF, 0xFF, 0xFF, 0xFF, 0xFF};

[[maybe_unused]] static bool s_espnowReady = false;

[[maybe_unused]] static void setupEspNow() {
  WiFi.mode(WIFI_STA);
  if (esp_now_init() != ESP_OK) {
    Serial.println("[ESP-NOW] 초기화 실패");
    return;
  }
  esp_now_peer_info_t peer = {};
  memcpy(peer.peer_addr, HAND_MAC, 6);
  peer.channel = 0;          // 현재 채널 사용 (두 보드 모두 WiFi 미연결이면 같은 채널)
  peer.ifidx = WIFI_IF_STA;
  peer.encrypt = false;
  if (esp_now_add_peer(&peer) != ESP_OK) {
    Serial.println("[ESP-NOW] 수신 보드 등록 실패");
    return;
  }
  s_espnowReady = true;
  Serial.print("[ESP-NOW] 준비 완료, 이 보드 MAC: ");
  Serial.println(WiFi.macAddress());
}

[[maybe_unused]] static void sendHandCommand(uint8_t cmd, uint8_t strength) {
  if (!s_espnowReady) return;
  const uint8_t pkt[2] = {cmd, strength};
  esp_err_t r = esp_now_send(HAND_MAC, pkt, SEND_STRENGTH ? 2 : 1);
  if (r != ESP_OK) Serial.printf("[ESP-NOW] 전송 실패 (%d)\n", (int)r);
}

// 판단 결과가 바뀌었을 때 호출됨
[[maybe_unused]] static void onOutputChanged(int gesture) {
  Serial.printf(">>> 출력 변경: %s (의수 명령 %d)\n", EMG_CLASS_NAMES[gesture],
                handCmdFor(gesture));
}

// ---------------------------------------------------------------------
// 힘 세기 (세게 주면 빠르게, 약하게 주면 천천히)
//
// "어떤 손가락인지"는 AI가 판단하고, "얼마나 세게 주는지"는 신호 크기로 따로 잽니다.
// (AI는 창마다 신호 크기를 똑같이 맞춘 뒤에 모양만 보기 때문에 세기를 알 수 없음)
//
//   세기(배) = 최근 0.2초 신호 크기가 쉴 때의 몇 배인지 (4채널 중 가장 큰 값)
//   세기(%)  = 휴식 게이트 크기를 0%, 아래 동작별 기준을 100%로 놓고 바꾼 값
//
// 같은 힘이라도 동작마다 신호 크기가 많이 달라서(약지 약 40배, 엄지 약 6배) 기준을 동작별로 둡니다.
// ---------------------------------------------------------------------
#define STRENGTH_WIN_MS  200    // 세기를 재는 구간 (최근 몇 ms)
#define STRENGTH_SMOOTH  0.5f   // 0~1. 작을수록 값이 부드럽지만 반응이 느림 (1이면 그대로)
#define STRENGTH_LEVELS  0      // 0 = 1~100 연속값 / 2 = 약,강 (50,100) / 3 = 약,중,강 (33,66,100)
#define STRENGTH_HYST    8.0f   // 단계로 나눌 때, 경계를 이만큼(%) 더 넘어야 단계가 바뀜 (깜빡임 방지)
#define STRENGTH_REPORT  1      // 동작이 끝날 때마다 세기 요약을 출력 (아래 기준 값을 맞출 때 사용)

// 동작별 100% 기준 = 평소 녹화하던 힘으로 줬을 때, 인식 직후 0.5초 동안의 평균 세기(배)
// (지금 data 폴더의 녹화 20개에서 구한 중앙값)
// - 센서를 다시 붙였거나 새로 녹화했으면: 평소 힘으로 몇 번 해보고 시리얼의
//   ">>> 세기 요약 ... 처음 0.5초 평균" 값으로 바꾸세요.
// - 평소 힘이 100%가 아니라 중간쯤이 되게 하려면 숫자를 키우면 됩니다 (예: 1.5배).
[[maybe_unused]] static float strengthFullFor(int gesture) {
  const char *n = EMG_CLASS_NAMES[gesture];
  if (!strcmp(n, "Thumb"))  return 6.4f;
  if (!strcmp(n, "Index"))  return 9.2f;
  if (!strcmp(n, "Middle")) return 23.0f;
  if (!strcmp(n, "Ring"))   return 40.0f;
  if (!strcmp(n, "Little")) return 7.8f;
  if (!strcmp(n, "Fist"))   return 21.0f;
  if (!strcmp(n, "Pinch"))  return 5.7f;
  return 10.0f;
}

// 세기(배) -> 0~100%
[[maybe_unused]] static float strengthPercent(int gesture, float ratio) {
  const float lo = (EMG_REST_GATE > 1.0f) ? EMG_REST_GATE : 1.5f;   // 이 크기 아래는 어차피 휴식
  float hi = strengthFullFor(gesture);
  if (hi < lo + 0.5f) hi = lo + 0.5f;
  const float p = (ratio - lo) / (hi - lo) * 100.0f;
  return p < 0.0f ? 0.0f : (p > 100.0f ? 100.0f : p);
}

// 세기(%) -> 의수로 보낼 값 (1~100). level에는 현재 단계를 기억해 둠 (0 = 아직 없음)
[[maybe_unused]] static uint8_t strengthToByte(float pct, uint8_t *level) {
#if STRENGTH_LEVELS >= 2
  const float w = 100.0f / STRENGTH_LEVELS;          // 한 단계의 폭 (%)
  int lv = (int)(pct / w) + 1;
  if (lv > STRENGTH_LEVELS) lv = STRENGTH_LEVELS;
  const int prev = *level;
  if (prev >= 1) {
    if (lv > prev && pct < prev * w + STRENGTH_HYST) lv = prev;          // 살짝 넘은 정도면 유지
    if (lv < prev && pct > (prev - 1) * w - STRENGTH_HYST) lv = prev;
  }
  *level = (uint8_t)lv;
  return (uint8_t)(lv * 100 / STRENGTH_LEVELS);
#else
  (void)level;
  const int v = (int)(pct + 0.5f);
  return (uint8_t)(v < 1 ? 1 : (v > 100 ? 100 : v));
#endif
}

// ---------------------------------------------------------------------
// 모드 전환 (MODE_RUN에서만 동작)
//   SW1 : 근전도 모드 <-> 매크로 모드
//   SW2 : 매크로 모드에서 다음 동작으로 넘김
//         (근전도 모드에서는 나중에 '사용자 보정'을 시작할 자리, 지금은 안내만 출력)
//
// 스위치가 없어도 아래 두 가지로 대신 누를 수 있습니다.
//   - 시리얼 모니터에서 1 전송 = SW1, 2 전송 = SW2
//   - 보드의 BOOT 버튼: 짧게 = SW2, 길게(0.8초) = SW1
// 스위치 핀: SW1 = D7(8번 패드), SW2 = D8(9번 패드). 서로 반대로 달렸으면 두 번호만 바꾸면 됩니다.
// (D7은 UART 수신 핀이기도 해서, Arduino IDE의 USB CDC On Boot가 Enabled여야 합니다)
// ---------------------------------------------------------------------
#define SW1_PIN         D7    // PCB 8번 패드. 스위치가 없는 보드면 -1
#define SW2_PIN         D8    // PCB 9번 패드. 스위치가 없는 보드면 -1
#define SW_PRESSED      LOW   // 누르면 GND에 연결되는 회로 기준 (내부 풀업 사용).
                              // 누르면 3.3V에 연결되는 회로면 HIGH로 변경
#define USE_SERIAL_KEYS 1     // 시리얼 1, 2 키로 스위치 흉내
#define USE_BOOT_BTN    1     // BOOT 버튼으로 스위치 흉내 (PCB가 오면 0으로 꺼도 됨)
#define BOOT_BTN_PIN    0     // XIAO ESP32-S3의 BOOT 버튼 (누르면 LOW)
#define LONG_PRESS_MS   800   // BOOT 버튼을 이 시간 이상 누르면 SW1로 처리

// 매크로 모드에서 SW2를 누를 때마다 이 순서로 넘어갑니다. {이름, 의수 명령 번호}
//   근전도 모드가 보내는 번호: 1~8   (엄지, 검지, 중지, 약지, 소지, 휴식, 주먹, 집게)
//   매크로 모드가 보내는 번호: 11~19 (의수 보드에서 번호별 동작을 정함)
// 매크로 모드에 들어가면 바로 첫 줄(11)을 보내고, 마지막(19) 다음은 다시 11입니다.
// 이름은 시리얼 출력용이라 동작이 정해지면 자유롭게 바꿔도 됩니다.
struct MacroItem { const char *name; uint8_t cmd; };
static const MacroItem MACROS[] = {
  {"매크로 1", 11},
  {"매크로 2", 12},
  {"매크로 3", 13},
  {"매크로 4", 14},
  {"매크로 5", 15},
  {"매크로 6", 16},
  {"매크로 7", 17},
  {"매크로 8", 18},
  {"매크로 9", 19},
};
#define MACRO_COUNT ((int)(sizeof(MACROS) / sizeof(MACROS[0])))

#define CTRL_EMG   0   // 근전도 모드
#define CTRL_MACRO 1   // 매크로 모드

#if RUN_MODE == MODE_RUN
static volatile uint8_t s_ctrlMode = CTRL_EMG;
static volatile uint8_t s_macroIdx = 0;

// SW1이 눌렸을 때: 모드 전환. LED가 켜져 있으면 매크로 모드
static void onSw1Pressed() {
  if (s_ctrlMode == CTRL_EMG) {
    s_macroIdx = 0;
    s_ctrlMode = CTRL_MACRO;
    Serial.printf("=== 매크로 모드 === 동작 1/%d: %s (의수 명령 %d)\n", MACRO_COUNT,
                  MACROS[0].name, MACROS[0].cmd);
  } else {
    s_ctrlMode = CTRL_EMG;
    Serial.println("=== 근전도 모드 === (휴식에서 다시 시작)");
  }
  digitalWrite(LED_BUILTIN, s_ctrlMode == CTRL_MACRO ? LOW : HIGH);
}

// SW2가 눌렸을 때
static void onSw2Pressed() {
  if (s_ctrlMode == CTRL_MACRO) {
    const uint8_t i = (uint8_t)((s_macroIdx + 1) % MACRO_COUNT);
    s_macroIdx = i;
    Serial.printf(">>> 매크로 동작 %d/%d: %s (의수 명령 %d)\n", i + 1, MACRO_COUNT,
                  MACROS[i].name, MACROS[i].cmd);
  } else {
    // TODO: 사용자 보정(마지막 층 다시 학습) 시작. 아직 구현 전
    Serial.println("[SW2] 근전도 모드: 사용자 보정은 아직 구현 전입니다");
  }
}

// 버튼 하나의 상태 (10ms마다 확인, 3번 연속 같은 값이어야 인정 = 떨림 제거)
#define BTN_NONE  0
#define BTN_SHORT 1
#define BTN_LONG  2
struct Button {
  int      pin;            // -1이면 없는 버튼
  int      pressedLevel;   // 눌렸을 때 핀 값 (LOW 또는 HIGH)
  bool     down;
  uint8_t  same;
  uint32_t downMs;
  bool     longDone;

  void begin(int p, int level) {
    pin = p; pressedLevel = level;
    down = false; same = 0; downMs = 0; longDone = false;
    if (pin >= 0) pinMode(pin, level == LOW ? INPUT_PULLUP : INPUT_PULLDOWN);
  }

  // useLong = false : 누르는 순간 BTN_SHORT
  // useLong = true  : 짧게 눌렀다 떼면 BTN_SHORT, LONG_PRESS_MS 이상 누르고 있으면 BTN_LONG
  int poll(bool useLong) {
    if (pin < 0) return BTN_NONE;
    const bool raw = (digitalRead(pin) == pressedLevel);
    if (raw == down) {
      same = 0;
    } else if (++same >= 3) {
      same = 0;
      down = raw;
      if (raw) {                                 // 눌림
        downMs = millis();
        longDone = false;
        if (!useLong) return BTN_SHORT;
      } else if (useLong && !longDone) {         // 짧게 눌렀다 뗌
        return BTN_SHORT;
      }
    }
    if (useLong && down && !longDone && millis() - downMs >= LONG_PRESS_MS) {
      longDone = true;
      return BTN_LONG;
    }
    return BTN_NONE;
  }
};

// 스위치 확인 전용 태스크 (코어 0). 1kHz 측정 루프(코어 1)는 건드리지 않음
static void ctrlTaskFn(void *arg) {
  (void)arg;
  Button sw1, sw2, boot;
  sw1.begin(SW1_PIN, SW_PRESSED);
  sw2.begin(SW2_PIN, SW_PRESSED);
  boot.begin(USE_BOOT_BTN ? BOOT_BTN_PIN : -1, LOW);

  for (;;) {
#if USE_SERIAL_KEYS
    while (Serial.available() > 0) {
      const int ch = Serial.read();
      if (ch == '1') onSw1Pressed();
      else if (ch == '2') onSw2Pressed();   // 줄바꿈 등 다른 글자는 무시
    }
#endif
    if (sw1.poll(false) == BTN_SHORT) onSw1Pressed();
    if (sw2.poll(false) == BTN_SHORT) onSw2Pressed();
    const int ev = boot.poll(true);
    if (ev == BTN_LONG) onSw1Pressed();
    else if (ev == BTN_SHORT) onSw2Pressed();
    vTaskDelay(pdMS_TO_TICKS(10));
  }
}
#endif  // RUN_MODE == MODE_RUN

// ---------------------------------------------------------------------
// 내부 동작 (보통 수정할 필요 없음)
// ---------------------------------------------------------------------
static const uint32_t SAMPLE_US = 1000000UL / EMG_FS;
static const uint32_t FIRST_DECISION = 500 + EMG_EPOCH_LEN;  // 필터 안정화 0.5초 + 1초

static EmgFilter s_filters[EMG_NUM_CH];
static uint32_t  s_count = 0;
static uint32_t  s_nextUs = 0;
static uint32_t  s_overruns = 0;

#if RUN_MODE == MODE_RUN || RUN_MODE == MODE_REPLAY
static float             s_ring[EMG_NUM_CH][EMG_EPOCH_LEN];
static uint32_t          s_ringPos = 0;
static float             s_epoch[EMG_NUM_CH * EMG_EPOCH_LEN];
static volatile bool     s_busy = false;
static volatile uint32_t s_epochEnd = 0;
static volatile uint32_t s_skipped = 0;   // 이전 판단이 안 끝나서 건너뛴 횟수 (0이어야 정상)
static TaskHandle_t      s_inferTask = NULL;
#endif

#if RUN_MODE == MODE_RECORD
// 측정과 전송을 분리: 측정은 코어 1에서 1kHz로, 전송은 코어 0에서
// (USB 전송이 잠깐 막혀도 샘플을 잃지 않게 하기 위함)
#define REC_BUF_SAMPLES 16384                 // 버퍼 크기
#define REC_MAX_BACKLOG 1000                  // 1초 넘게 밀리면 PC가 안 읽는 중으로 보고 최신 데이터부터 보냄
static int16_t      s_recBuf[REC_BUF_SAMPLES][REC_CH];
static volatile uint32_t s_recHead = 0;       // 측정이 쓴 위치
static volatile uint32_t s_recTail = 0;       // 전송이 읽은 위치
static volatile uint32_t s_recLost = 0;       // 버퍼가 가득 차서 버린 샘플 수
static TaskHandle_t s_sendTask = NULL;
static volatile uint32_t s_lastDropMs = 0;

static void sendTaskFn(void *arg) {
  (void)arg;
  char line[48];
  for (;;) {
    const uint32_t head = s_recHead;
    // GUI가 아직 안 읽고 있으면 데이터가 쌓임 -> 오래된 건 버리고 실시간으로 맞춤
    // (쌓인 옛날 데이터가 녹화 앞부분에 섞여 라벨이 밀리는 것을 막음)
    if (head - s_recTail > REC_MAX_BACKLOG) {
      s_recTail = head;
      s_lastDropMs = millis();
    }
    // LED: 데이터를 버리는 중이면 켜짐. 녹화 중에는 꺼져 있어야 정상
    digitalWrite(LED_BUILTIN, (millis() - s_lastDropMs < 300) ? LOW : HIGH);
    if (s_recTail == head) {                  // 보낼 게 없으면 잠깐 쉼
      vTaskDelay(1);
      continue;
    }
    const uint32_t idx = s_recTail % REC_BUF_SAMPLES;
    int len = snprintf(line, sizeof(line), "%d.0,%d.0,%d.0,%d.0\r\n",
                       s_recBuf[idx][0], s_recBuf[idx][1], s_recBuf[idx][2], s_recBuf[idx][3]);
    Serial.write((const uint8_t *)line, len);
    s_recTail = s_recTail + 1;
  }
}
#endif

#if RUN_MODE == MODE_REPLAY
static uint32_t s_replayVec = 0;
static uint32_t s_replayIdx = 0;
#endif

#if RUN_MODE == MODE_CHECK
static double   s_sum[REC_CH];
static double   s_sq[REC_CH];
static double   s_rawSum[REC_CH];
static uint32_t s_clip[REC_CH];
static uint32_t s_statN = 0;
#endif

#if RUN_MODE == MODE_RUN || RUN_MODE == MODE_REPLAY
static void inferTaskFn(void *arg) {
  (void)arg;
  EmgVote vote;
  emg_vote_reset(&vote);
  int lastOutput = EMG_REST_CLASS;
  float probs[EMG_NUM_CLASSES];

  // 힘 세기
  float   strengthPct = 0.0f;     // 부드럽게 만든 세기 (%)
  uint8_t strengthLevel = 0;      // 단계로 나눌 때의 현재 단계
  const int earlyN = (500 / EMG_STEP_LEN) > 0 ? (500 / EMG_STEP_LEN) : 1;   // 처음 0.5초 = 판단 몇 번
  float sumEarly = 0.0f, sumLate = 0.0f;   // 세기 요약용
  int   nEarly = 0, nLate = 0;

#if RUN_MODE == MODE_RUN
  uint8_t prevMode = CTRL_EMG;
#endif

  for (;;) {
    ulTaskNotifyTake(pdTRUE, portMAX_DELAY);

#if RUN_MODE == MODE_RUN
    const uint8_t mode = s_ctrlMode;
    if (mode == CTRL_MACRO) {
      // 매크로 모드: 근전도 판단은 하지 않고, 고른 동작을 판단 주기마다 계속 보냄
      // (한 번 못 받아도 다음 전송에서 복구됨. 의수 보드는 같은 명령이 반복되면 무시)
      prevMode = mode;
#if USE_ESPNOW
      sendHandCommand(MACROS[s_macroIdx].cmd, 0);
#endif
      s_busy = false;
      continue;
    }
    if (prevMode != mode) {
      // 매크로 -> 근전도로 돌아온 직후: 예전 판단 기록을 지우고 휴식에서 다시 시작
      emg_vote_reset(&vote);
      lastOutput = EMG_REST_CLASS;
      strengthPct = 0.0f;
      strengthLevel = 0;
      prevMode = mode;
    }
#endif

    uint32_t t0 = micros();
    int pred = emg_classify(s_epoch, probs);
    pred = emg_rest_gate(s_epoch, pred);        // 신호가 휴식 수준이면 무조건 휴식
    int output = emg_vote_update(&vote, pred);
    uint32_t dtMs = (micros() - t0) / 1000UL;

    // ---- 힘 세기 ----
    const float ratio = emg_strength(s_epoch, STRENGTH_WIN_MS * EMG_FS / 1000);   // 쉴 때의 몇 배
    uint8_t strengthOut = 0;                       // 의수로 보낼 값 (0 = 세기 정보 없음)
    if (output != lastOutput) strengthLevel = 0;
    if (output == EMG_REST_CLASS) {
      strengthPct = 0.0f;
    } else {
      const float p = strengthPercent(output, ratio);
      if (output != lastOutput) strengthPct = p;                    // 동작이 시작된 순간에는 바로 반영
      else strengthPct += STRENGTH_SMOOTH * (p - strengthPct);      // 그 뒤로는 부드럽게 따라감
      strengthOut = strengthToByte(strengthPct, &strengthLevel);
    }

    static uint32_t s_decisions = 0;
    s_decisions++;
    const bool printAll = (EMG_STEP_LEN >= 200);                   // 느린 모드: 매번 출력
    const bool printNow = printAll || output != lastOutput ||
                          (s_decisions % (1000 / EMG_STEP_LEN) == 0); // 빠른 모드: 바뀔 때 + 1초마다
    if (printNow) {
    Serial.printf("[%7.2fs] 판단 %-6s %3.0f%% | 출력 %-6s | RMS",
                  s_epochEnd / (float)EMG_FS, EMG_CLASS_NAMES[pred], probs[pred] * 100.0f,
                  EMG_CLASS_NAMES[output]);
    for (int c = 0; c < EMG_NUM_CH; ++c) {
      double acc = 0.0;
      const float *x = s_epoch + c * EMG_EPOCH_LEN;
      for (int n = 0; n < EMG_EPOCH_LEN; ++n) acc += (double)x[n] * x[n];
      Serial.printf(" %4.0f", sqrt(acc / EMG_EPOCH_LEN));
    }
    Serial.printf(" | 세기 %4.1f배 %3d%%", ratio, (int)strengthOut);
    Serial.printf(" | %lu ms", (unsigned long)dtMs);
#if RUN_MODE == MODE_REPLAY
    Serial.printf(" | 재생 중: %s", EMG_CLASS_NAMES[EMG_TEST_LABEL[s_replayVec]]);
#endif
    if (s_overruns) Serial.printf(" | 측정 지연 %lu회", (unsigned long)s_overruns);
    if (s_skipped) Serial.printf(" | 판단 건너뜀 %lu회", (unsigned long)s_skipped);
    Serial.println();
    }

    if (output != lastOutput) {
      onOutputChanged(output);
#if STRENGTH_REPORT
      if (lastOutput != EMG_REST_CLASS && nEarly > 0) {   // 방금 끝난 동작의 세기 요약
        Serial.printf(">>> 세기 요약 %s: 처음 0.5초 평균 %.1f배 (100%% 기준 %.1f배)",
                      EMG_CLASS_NAMES[lastOutput], sumEarly / nEarly, strengthFullFor(lastOutput));
        if (nLate > 0) Serial.printf(", 그 뒤 평균 %.1f배", sumLate / nLate);
        Serial.println();
      }
#endif
      sumEarly = sumLate = 0.0f;
      nEarly = nLate = 0;
      lastOutput = output;
    }
    if (output != EMG_REST_CLASS) {                // 세기 요약용 누적
      if (nEarly < earlyN) { sumEarly += ratio; nEarly++; }
      else                 { sumLate += ratio;  nLate++; }
    }
#if RUN_MODE == MODE_RUN && USE_ESPNOW
    // 판단할 때마다 현재 명령과 힘 세기를 보냄 (바뀌면 바로 반영되고, 한 번 못 받아도 다음에 복구됨)
    sendHandCommand(handCmdFor(output), strengthOut);
#endif
    s_busy = false;
  }
}
#endif

static void sampleOnce() {
  int x[REC_CH] = {0};
#if RUN_MODE == MODE_REPLAY
  for (int c = 0; c < EMG_NUM_CH; ++c) x[EMG_CHANNEL_IDX[c]] = EMG_TEST_RAW[s_replayVec][c][s_replayIdx];
#else
  for (int c = 0; c < REC_CH; ++c) x[c] = readEmgInput(c);
#endif
  s_count++;

#if RUN_MODE == MODE_RECORD
  // 버퍼에 넣기만 하고, 전송은 다른 코어가 담당 (측정이 멈추지 않도록)
  if (s_recHead - s_recTail < REC_BUF_SAMPLES) {
    const uint32_t idx = s_recHead % REC_BUF_SAMPLES;
    for (int c = 0; c < REC_CH; ++c) s_recBuf[idx][c] = (int16_t)x[c];
    s_recHead = s_recHead + 1;
  } else {
    s_recLost = s_recLost + 1;                // 버퍼까지 가득 차면 그때만 손실
  }
  return;
#endif

#if RUN_MODE == MODE_CHECK
  for (int c = 0; c < REC_CH; ++c) {
    s_sum[c] += x[c];
    s_sq[c] += (double)x[c] * x[c];
    s_rawSum[c] += s_lastRaw[c];
    // 클리핑은 필터 전 원본 값(0~4095) 기준으로 확인
    if (s_lastRaw[c] <= 5 || s_lastRaw[c] >= 4090) s_clip[c]++;
  }
  if (++s_statN >= (uint32_t)EMG_FS) {
    Serial.printf("[%6.1fs] 원본평균", s_count / (float)EMG_FS);
    for (int c = 0; c < REC_CH; ++c) Serial.printf(" %5.0f", s_rawSum[c] / s_statN);
    Serial.print(" | 흔들림(표준편차)");
    for (int c = 0; c < REC_CH; ++c) {
      double m = s_sum[c] / s_statN;
      double v = s_sq[c] / s_statN - m * m;
      Serial.printf(" %4.0f", v > 0 ? sqrt(v) : 0.0);
    }
    Serial.print(" | 클리핑");
    for (int c = 0; c < REC_CH; ++c) Serial.printf(" %3lu", (unsigned long)s_clip[c]);
    if (s_overruns) Serial.printf(" | 측정 지연 %lu회", (unsigned long)s_overruns);
    Serial.println();
    for (int c = 0; c < REC_CH; ++c) { s_sum[c] = 0.0; s_sq[c] = 0.0; s_rawSum[c] = 0.0; s_clip[c] = 0; }
    s_statN = 0;
  }
  return;
#endif

#if RUN_MODE == MODE_RUN || RUN_MODE == MODE_REPLAY
  for (int c = 0; c < EMG_NUM_CH; ++c) {
    s_ring[c][s_ringPos] = emg_filter_step(&s_filters[c], (float)x[EMG_CHANNEL_IDX[c]]);
  }
  s_ringPos = (s_ringPos + 1) % EMG_EPOCH_LEN;

#if RUN_MODE == MODE_REPLAY
  if (++s_replayIdx >= (uint32_t)EMG_TEST_LEN) {
    s_replayIdx = 0;
    s_replayVec = (s_replayVec + 1) % EMG_TEST_COUNT;
  }
#endif

  if (s_count >= FIRST_DECISION && (s_count - FIRST_DECISION) % EMG_STEP_LEN == 0 && s_busy) {
    s_skipped = s_skipped + 1;   // 판단 주기가 계산 시간보다 짧음
  }
  if (s_count >= FIRST_DECISION && (s_count - FIRST_DECISION) % EMG_STEP_LEN == 0 && !s_busy) {
    for (int c = 0; c < EMG_NUM_CH; ++c) {
      float *dst = s_epoch + c * EMG_EPOCH_LEN;
      const uint32_t tail = EMG_EPOCH_LEN - s_ringPos;
      memcpy(dst, &s_ring[c][s_ringPos], tail * sizeof(float));
      memcpy(dst + tail, &s_ring[c][0], s_ringPos * sizeof(float));
    }
    s_epochEnd = s_count;
    s_busy = true;
    xTaskNotifyGive(s_inferTask);
  }
#endif
}

void setup() {
  Serial.begin(115200);
  setupEmgInput();
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
void loop() {
  const uint32_t now = micros();
  if ((int32_t)(now - s_nextUs) < 0) return;  // 아직 1ms가 안 됨
  s_nextUs += SAMPLE_US;
  if ((int32_t)(now - s_nextUs) > (int32_t)(200 * SAMPLE_US)) {
    s_nextUs = now + SAMPLE_US;  // 0.2초 넘게 밀리면 포기하고 다시 맞춤
    s_overruns++;
  }
  sampleOnce();
}

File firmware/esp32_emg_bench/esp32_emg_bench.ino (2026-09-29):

// =====================================================================
// 판단 속도 측정 (센서 없이 실행)
//   1) 필터            : 1초치(4채널 1000샘플) 필터 계산
//   2) STFT 특징       : 정규화 + FFT + 주파수 묶기
//   3) CNN             : 전체 판단 시간에서 특징 시간을 뺀 값
//   4) 시간영역 방식   : 특징(MAV/RMS/파형길이/영교차/기울기) + 작은 신경망
//                        (속도 비교용이라 가중치는 임의값)
// =====================================================================
#include "emg_infer.h"
#include "emg_test_vectors.h"

static float s_epoch[EMG_NUM_CH * EMG_EPOCH_LEN];
static float s_feat[EMG_NUM_CH * EMG_NUM_BANDS * EMG_NUM_FRAMES];
static float s_probs[EMG_NUM_CLASSES];

// ---- 시간영역 방식 (비교용) ----
#define TD_SUB    4                       // 1초를 4구간으로 나눔
#define TD_IN     (EMG_NUM_CH * TD_SUB * 5)  // 채널 x 구간 x 특징 5개
#define TD_HIDDEN 48
static float td_feat[TD_IN];
static float td_w1[TD_IN * TD_HIDDEN], td_b1[TD_HIDDEN];
static float td_w2[TD_HIDDEN * TD_HIDDEN], td_b2[TD_HIDDEN];
static float td_w3[TD_HIDDEN * EMG_NUM_CLASSES], td_b3[EMG_NUM_CLASSES];
static float td_h1[TD_HIDDEN], td_h2[TD_HIDDEN];

static uint32_t rnd = 1;
static float frand() { rnd = rnd * 1664525UL + 1013904223UL; return ((rnd >> 8) & 0xFFFF) / 32768.0f - 1.0f; }

static void td_init() {
  for (int i = 0; i < TD_IN * TD_HIDDEN; ++i) td_w1[i] = frand() * 0.1f;
  for (int i = 0; i < TD_HIDDEN; ++i) td_b1[i] = 0.0f;
  for (int i = 0; i < TD_HIDDEN * TD_HIDDEN; ++i) td_w2[i] = frand() * 0.1f;
  for (int i = 0; i < TD_HIDDEN; ++i) td_b2[i] = 0.0f;
  for (int i = 0; i < TD_HIDDEN * EMG_NUM_CLASSES; ++i) td_w3[i] = frand() * 0.1f;
  for (int i = 0; i < EMG_NUM_CLASSES; ++i) td_b3[i] = 0.0f;
}

static void td_features(const float *epoch) {
  const int sub = EMG_EPOCH_LEN / TD_SUB;
  int k = 0;
  for (int c = 0; c < EMG_NUM_CH; ++c) {
    const float *x = epoch + c * EMG_EPOCH_LEN;
    for (int s = 0; s < TD_SUB; ++s) {
      const float *p = x + s * sub;
      float mav = 0, sq = 0, wl = 0;
      int zc = 0, ssc = 0;
      for (int n = 0; n < sub; ++n) { mav += fabsf(p[n]); sq += p[n] * p[n]; }
      mav /= sub;
      float rms = sqrtf(sq / sub);
      float th = 0.15f * rms;
      for (int n = 1; n < sub; ++n) {
        float d = p[n] - p[n - 1];
        wl += fabsf(d);
        if (p[n] * p[n - 1] < 0 && fabsf(d) > th) zc++;
        if (n > 1 && (p[n] - p[n - 1]) * (p[n - 1] - p[n - 2]) < 0 && fabsf(d) > th) ssc++;
      }
      wl /= (sub - 1);
      td_feat[k++] = logf(mav + 1e-3f);
      td_feat[k++] = logf(rms + 1e-3f);
      td_feat[k++] = logf(wl + 1e-3f);
      td_feat[k++] = (float)zc / sub;
      td_feat[k++] = (float)ssc / sub;
    }
  }
}

static int td_classify(const float *epoch) {
  td_features(epoch);
  for (int j = 0; j < TD_HIDDEN; ++j) {
    float a = td_b1[j];
    for (int i = 0; i < TD_IN; ++i) a += td_w1[j * TD_IN + i] * td_feat[i];
    td_h1[j] = a > 0 ? a : 0;
  }
  for (int j = 0; j < TD_HIDDEN; ++j) {
    float a = td_b2[j];
    for (int i = 0; i < TD_HIDDEN; ++i) a += td_w2[j * TD_HIDDEN + i] * td_h1[i];
    td_h2[j] = a > 0 ? a : 0;
  }
  int best = 0;
  float bestv = -1e30f;
  for (int j = 0; j < EMG_NUM_CLASSES; ++j) {
    float a = td_b3[j];
    for (int i = 0; i < TD_HIDDEN; ++i) a += td_w3[j * TD_HIDDEN + i] * td_h2[i];
    if (a > bestv) { bestv = a; best = j; }
  }
  return best;
}

static const int REPEAT = 20;

void setup() {
  Serial.begin(115200);
  delay(3000);
  Serial.println();
  Serial.println("===== 판단 속도 측정 =====");
  td_init();

  // 테스트 데이터 1초치를 필터에 통과시켜 준비
  EmgFilter f[EMG_NUM_CH];
  for (int c = 0; c < EMG_NUM_CH; ++c) emg_filter_reset(&f[c]);
  for (int n = 0; n < EMG_TEST_LEN; ++n) {
    for (int c = 0; c < EMG_NUM_CH; ++c) {
      float y = emg_filter_step(&f[c], (float)EMG_TEST_RAW[4][c][n]);
      int m = n - (EMG_TEST_LEN - EMG_EPOCH_LEN);
      if (m >= 0) s_epoch[c * EMG_EPOCH_LEN + m] = y;
    }
  }

  uint32_t t0 = micros();
  for (int r = 0; r < REPEAT; ++r) {
    for (int c = 0; c < EMG_NUM_CH; ++c) emg_filter_reset(&f[c]);
    for (int n = 0; n < EMG_EPOCH_LEN; ++n)
      for (int c = 0; c < EMG_NUM_CH; ++c) emg_filter_step(&f[c], (float)EMG_TEST_RAW[4][c][n]);
  }
  float tFilter = (micros() - t0) / 1000.0f / REPEAT;

  t0 = micros();
  for (int r = 0; r < REPEAT; ++r) emg_features(s_epoch, s_feat);
  float tFeat = (micros() - t0) / 1000.0f / REPEAT;

  t0 = micros();
  for (int r = 0; r < REPEAT; ++r) emg_classify(s_epoch, s_probs);
  float tAll = (micros() - t0) / 1000.0f / REPEAT;

  t0 = micros();
  for (int r = 0; r < REPEAT; ++r) td_classify(s_epoch);
  float tTd = (micros() - t0) / 1000.0f / REPEAT;

  Serial.printf("필터 (1초치, 1000샘플 x 4채널) : %7.2f ms\n", tFilter);
  Serial.printf("STFT 특징 계산                 : %7.2f ms\n", tFeat);
  Serial.printf("CNN 계산                       : %7.2f ms\n", tAll - tFeat);
  Serial.printf("합계 (지금 방식, 판단 1번)     : %7.2f ms\n", tAll);
  Serial.printf("시간영역 특징 + 작은 신경망     : %7.2f ms\n", tTd);
  Serial.printf("\n0.5초(500ms)마다 판단하므로 여유: 지금 방식 %.0f%%, 시간영역 %.0f%% 사용\n",
                100.0f * tAll / 500.0f, 100.0f * tTd / 500.0f);
}

void loop() { delay(1000); }

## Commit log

2026-09-29 Initial commit: ReHand EMG prosthesis control system
    - hardware: KiCad EMG board (XIAO ESP32-S3 + 4ch sensor connectors) and gerbers
    - collector: PySide6 data collection GUI
    - training: PyTorch STFT-CNN training and ESP32 C header export
    - firmware: realtime inference, golden test, and benchmark sketches
    - docs: hand board ESP-NOW patch notes and result figures
    [EMG-B_Cu.gbr, EMG-B_Mask.gbr, EMG-B_Paste.gbr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]
2026-09-30 Add EMG board v2 and split hardware into v1/v2
    - hardware/v2: XIAO SMD footprint, PicoBlade battery input, two buttons
    with pull-up + RC debounce; KiCad project and gerbers
    - move previous board to hardware/v1
    - README: v1/v2 comparison, renders and schematics; drop ESP-NOW from tech stack
    [EMG-B_Cu.gbr, EMG-B_Mask.gbr, EMG-B_Paste.gbr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]
2026-10-02 Tighten fast-mode output voting to cut false activations
    - add release_n (consecutive rest decisions to turn off) and minimum
    hold time to vote logic in both train_emg.py and emg_infer.cpp
    - fast preset: switch 5 -> 8, release 1 -> 3, hold 0.5 s
    - fast mode: false activations 15 -> 6 per 6.7 min, release 104 -> 243 ms
    - README: update performance table and troubleshooting #7
    [esp32_emg_realtime.ino]
2026-10-06 Add EMG/macro control modes with SW1/SW2 buttons
    - firmware: SW1 toggles EMG <-> macro mode, SW2 steps macro commands 11-19;
    dedicated FreeRTOS task polls buttons every 10 ms with debounce;
    serial keys and BOOT button as fallback input
    - README: describe v2 button functions
    - hand_board_patch: note that hand board must accept commands 11-19
2026-10-07 Send grip strength with gesture command; add changelog
    - emg_strength(): recent 0.2 s RMS relative to rest RMS (max over channels)
    - per-gesture 100% reference, smoothing, optional level output with hysteresis,
    per-gesture strength summary on serial for recalibration
    - ESP-NOW packet is now {command, strength}; SEND_STRENGTH=0 keeps 1-byte format
    - hand_board_patch: how the hand board should read strength and map it to servo speed
    - README: strength section, diagram update, changelog
2026-10-13 모드 선택(emg_mode.h) 및 SW1 3초 의수 호밍 추가
2026-10-15 의수 호밍을 SW2 3초로 변경
2026-10-23 MIT 라이선스 추가
    외부 코드(EMGFilters, BSD-3-Clause)는 원본 라이선스를 따름을 README에 명시
2026-11-01 중간 모드 추가, 휴식 게이트 켜기, 손가락 전환 시 휴식 거치기
    - 중간 모드(EMG_FAST_MODE 2): 0.75초 창, 100ms마다 판단. 학습 결과 정확도 96.4%,
    제어 지연 중앙값 356ms. 기본 모드를 중간 모드로 변경
    - train_emg.py --mid 옵션과 MID_PRESET 추가, 결과는 training/output_mid
    - 정확 모드: 휴식 게이트 2.0, Rest 2번 연속이면 끄기
    - 손가락 -> 다른 손가락은 반드시 휴식을 거쳐야 바뀜 (EMG_SWITCH_VIA_REST)
    - 예외로 주먹(Fist)은 휴식 없이 바로 바뀜 (EMG_SWITCH_FREE_MASK, 설정 switch_free_classes)
    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
2026-11-01 판단 방식을 0.75초 창 · 100ms 주기 하나로 통일
    - 정확/빠른 모드와 emg_mode.h 선택 삭제, 중간 모드 모델을 emg_model.h로 사용
    - train_emg.py 기본 설정을 0.75초 창 · 100ms 주기로 바꾸고 --fast/--mid 옵션 삭제
    - 학습 결과를 training/output 하나로 정리 (output_fast, output_mid 삭제)
    - 시리얼 첫 줄에 판단 창 · 주기 출력
    - README 성능 표와 그림, 변경 이력, 의수 보드 문서 갱신
2026-11-01 README에 연락처 추가
2026-11-12 v2 추가: 스트리밍 특징 + 1D CNN(TCN) 판단, 의수 펌웨어 개선
    - training/train_v2.py: 25ms마다 계산하는 특징 22개 + 과거만 보는 TCN 학습, 펌웨어 헤더 자동 생성
    - firmware/emg_board_v2: 스트리밍 추론, 의수와 양방향 ESP-NOW 연결, 사용자 보정, 잠금 모드
    - firmware/hand_board_v2: 힘 세기 비례 속도·쥐는 힘, 멈추지 않는 동작 순서, 호밍 태스크 분리, 서보 상태 감시
    - training/host_check.py: 펌웨어 C 코드를 PC에서 컴파일해 PyTorch와 프레임 단위 대조
    - docs/v2_guide.md, docs/v2_results.md: 사용 방법과 실험 결과
    Random 5세션 기준 창 단위 정확도 96.4% -> 98.7%, 제어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
2026-11-12 README 브랜치 안내 갱신 (main, v1-stft-cnn, v2-only)
2026-11-12 emg2_model.pt에 PC 폴더 경로가 저장되지 않게 수정
    host_check.py는 모델 파일에 저장된 경로 대신 실행하는 PC의 데이터 폴더를 사용.
    모델 가중치는 그대로이고, host_check.py 32,014프레임 대조 통과.
2026-11-12 v2 링크: 연결된 상대 보드의 패킷만 받도록 수정 (#1)
    - 의수: 처음 명령을 보낸 근전도 보드의 주소를 NVS에 저장하고, 그 뒤로는 그 주소에서 온 명령만 실행.
    다른 주소에서 온 명령(v2 형식, 예전 1~2바이트 형식 모두)은 버리고 개수를 셈
    - 의수: 연결 상대 지우기 추가 (시리얼 p, BOOT 버튼 3초), 상태 출력(?)에 연결 상대와 무시한 명령 수 표시
    - 근전도 보드: 연결된 의수의 상태만 받음. 의수가 1.5초 넘게 조용하면 연결을 풀고 방송으로 다시 찾음
    - 주소 확인만 하고 암호화는 하지 않음 (주소를 흉내 내는 송신기는 막지 못함)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
2026-11-12 README 변경 이력: 연결 상대 고정
